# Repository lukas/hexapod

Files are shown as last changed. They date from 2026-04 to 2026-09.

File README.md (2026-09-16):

# Robotics projects

This repository contains the current hexapod work plus a small collection of
related robot builds and shared tooling. The hexapod history was extracted
(with full Git history and `exp/*` provenance tags) from the `weird_objects`
monorepo on 2026-08-29.

The top-level `hexapod_walker/` directory is kept intentionally — the RL
orchestrator, Makefiles, and provenance records use repo-root-relative
paths like `hexapod_walker/prototype_sts3215/...`, and preserving the
layout kept the extraction risk-free.

## Project families

- [`hexapod_walker/`](hexapod_walker/) — active hexapods, earlier actuator
  variants, and frozen walker generations.
- [`vehicles/`](vehicles/) — wheeled robot projects that do not share the
  hexapod architecture. The TT-motor kid truck lives here.
- [`tools/`](tools/) — repository-wide utilities used by more than one project.
- [`media/`](media/) — checked-in media referenced by project records.
- Robot Lab v2 (the experiment queue, loop and web/MCP service) lives in
  [lukas/hexapod-lab](https://github.com/lukas/hexapod-lab); it runs against a clone of this repo.

The current robot is
[`hexapod_walker/prototype_sts3215/`](hexapod_walker/prototype_sts3215/): an
18-servo Feetech STS3215 hexapod with MuJoCo/RL, robot control, and an
AprilTag tracker submodule. Start with that project's `README.md` and
`AGENTS.md`. The mechanical design (CAD, BOM, printing, BuildViz) is the
separate repo [lukas/hexapod-cad](https://github.com/lukas/hexapod-cad).

The hexapod has [two parallel walking goals](https://github.com/lukas/hexapod-orchestrator/blob/main/RL_GOALS.md):
smooth joystick control in simulation and on the physical robot by any
effective means, and that same result with walking learned entirely through RL without
demonstrations. The practical path keeps physical builds progressing while
the demonstration-free research continues.

`pyproject.toml` and `uv.lock` at the repository root define the ONE Python
environment for the whole repo: `uv sync` creates `.venv`, and `uv run ...`
uses it from any directory. The prototype packages are installed editable,
so `import rl_move` / `import hexapod_core` / the bare-module style used by
`linux_control/` and `motor_setup/` work without `sys.path` shims. `run.sh`
is the script runner the Makefiles use (it syncs the env, then runs a script
from its own directory).

The autonomous RL orchestrator (watcher, launcher, status server, MCP
server), the research-process rules (`RESEARCH_RULES.md`, `RL_PLAN.md`,
`RL_GOALS.md`, `EMERGENCY_HANDLING.md`, ...) and the runtime state it writes
(ledger, run stories, cycle log) live in their own repo,
[lukas/hexapod-orchestrator](https://github.com/lukas/hexapod-orchestrator). Sim tools here read the ledger
from `$HEXAPOD_STATE_DIR` (`rl_move/ledger.py`).

After a fresh clone, initialize the tracker submodule:

```sh
git submodule update --init --recursive
```

## Conventions

See `AGENTS.md` (uv, BuildViz, hardware safety) and `.cursor/rules/`
(local dev environment, worktrees, STS3215 hardware safety).

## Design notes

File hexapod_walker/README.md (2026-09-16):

# Hexapod Walker

A family of six-legged walking-robot designs, from a tabletop 3D-printed
prototype up to a human-carrying vehicle.

| Directory | What it is |
|---|---|
| [`prototype_sts3215/`](prototype_sts3215/) | **Current robot** — Feetech STS3215 serial-bus servos, Arduino UNO Q brain, full CAD validation pipeline, MuJoCo RL stack (its CoreWeave orchestrator is [lukas/hexapod-orchestrator](https://github.com/lukas/hexapod-orchestrator)), web control, and the `hexapod-tracker` submodule. See [`prototype_sts3215/PROTOTYPE.md`](prototype_sts3215/PROTOTYPE.md), [`prototype_sts3215/docs/CAD_WORKFLOW.md`](prototype_sts3215/docs/CAD_WORKFLOW.md), and the [`concepts/` index](prototype_sts3215/concepts/README.md). |
| `prototype_ak40/` | AK40-actuator concept variant; moved to [lukas/hexapod-cad](https://github.com/lukas/hexapod-cad) on 2026-09-15 with the rest of the CAD. |

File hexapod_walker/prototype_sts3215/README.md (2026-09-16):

# Hexapod STS3215 prototype

Tabletop 3D-printed hexapod driven by Feetech STS3215 bus servos and an
Arduino Uno Q. We pursue [two goals in parallel](https://github.com/lukas/hexapod-orchestrator/blob/main/RL_GOALS.md): smooth
joystick walking in simulation and on the physical robot by any effective
means, and the same outcome with
walking learned entirely through RL, without demonstrations. The first path
keeps physical builds progressing while the harder research continues.

The work is split into four areas that share the robot; start at the entry
point for the one you're working on:

| You are here to… | Start at |
|---|---|
| Design/print/assemble the robot (CAD, BOM) | separate repo: [lukas/hexapod-cad](https://github.com/lukas/hexapod-cad) (`PROTOTYPE.md` there) |
| Run the physical robot (firmware, control, safety) | `firmware/`, `linux_control/`, `rl_move/API.md` — **read the hardware-safety rules in the repo root `AGENTS.md` first** |
| Train it in simulation (RL campaign + autonomous agent loop) | [`rl_docs/README.md`](rl_docs/README.md) (doc index) here; the goals, plan, rules and the autonomous loop are the separate repo [lukas/hexapod-orchestrator](https://github.com/lukas/hexapod-orchestrator) (`RL_GOALS.md`, `RL_PLAN.md`, `RESEARCH_RULES.md` at its root) |
| See and steer either goal in simulation | [`sim_viewer/README.md`](sim_viewer/README.md) — viewer/joystick controls; verify the selected policy and configuration against the goal's demo evidence |
| Track it with cameras and AprilTags | [`hexapod-tracker/README.md`](hexapod-tracker/README.md) — standalone submodule with its own package, configs, UI, tests, and agent instructions |

## Status URLs

- Agent/orchestrator dashboard:
  `https://hexapod.cwd1f0-new-cluster.coreweave.app/now`
  (token-gated).
- Agent/LLM-readable status index:
  `https://hexapod.cwd1f0-new-cluster.coreweave.app/llms.txt`
  (no token).
- Local robot/sim control UI:
  `http://localhost:8898/rl`
  via `make web-8898-start`.

## Layout

| Path | What |
|---|---|
| `hexapod_core/` | The executable contracts every layer shares: `joint_frame.py` (joint order, names, servo ids), `geometry.py` (frozen CAD dimensions), gaits |
| `mujoco_prototype.py` | MuJoCo primitive model of the robot, built from `hexapod_core/geometry.py` |
| `mesh_mujoco/` | As-built MuJoCo mesh model; the STL assets and XML are tracked build products of [lukas/hexapod-cad](https://github.com/lukas/hexapod-cad) |
| [`docs/`](docs/) | Robot-side design notes still referenced by code; CAD, BOM and BuildViz docs live in hexapod-cad |
| `Makefile` | Tests, state pull, robot deploy, Mac hub |
| `firmware/` / `linux_control/` / `motor_setup/` | On-robot software |
| `hexapod-tracker/` | Git submodule containing AprilTag tracking, camera server/UI, configs, and off-robot vision tests |
| `rl_docs/` | RL campaign docs index: goal, operator wishlist, commands, log conventions |
| `rl_move/` | RL code: `sim/` (MuJoCo/MJX envs + training), robot-side control; the autonomous loop (watcher, launcher, guardrails) is [lukas/hexapod-orchestrator](https://github.com/lukas/hexapod-orchestrator) |
| `logs/` | Eval artifacts + per-experiment summaries (`logs/experiments/<run>/`) |
| `archive/` | Dated reviews, rulings, full plan/log history — search, don't read |

## Quick commands

Local Python convention: use `uv run python ...` or `uv run python -m ...`;
do not copy old bare `python3` examples from logs/archive. The repo-root
`AGENTS.md` and this project's `AGENTS.md` record the rule. Native
MuJoCo GUI/viewer launches on macOS are the special exception: use
`uv run mjpython ...` or the Makefile viewer targets.

After a fresh clone, initialize the tracker with `git submodule update --init`.

```sh
make -C hexapod_walker/prototype_sts3215 help
make -C hexapod_walker/prototype_sts3215 build
make -C hexapod_walker/prototype_sts3215 verify-fast
make -C hexapod_walker/prototype_sts3215 robot-check       # safe local robot/web checks
make -C hexapod_walker/prototype_sts3215 robot-deploy      # check + SSH deploy + remote health
make -C hexapod_walker/prototype_sts3215 web-8898-restart  # Mac hub: HTTPS :8443 + HTTP :8898
```

Robot-control dev loop details live in `linux_control/README.md` and
`linux_control/dev_loop.sh`. Use `robot-resolve` for a temporary IP when
`hexapod.local` is flaky; do not commit fixed board IPs.

The canonical local browser/control surface is `make -C
hexapod_walker/prototype_sts3215 web-8898-start`. It runs on the Mac via
`uv run`, manages a `launchctl` job, dynamically resolves the robot's
`:8080` service unless `HEXAPOD_HOST` is set, and serves
`https://localhost:8443/rl` for gamepad access, with the legacy
`http://localhost:8898/rl` still available. Accept the self-signed certificate
warning once. Use `web-8898-status`, `web-8898-restart`, `web-8898-stop`, and
`web-8898-logs` for operations.

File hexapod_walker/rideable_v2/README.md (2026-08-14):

# Rideable Hexapod Walker — `rideable_v2`

> A one-rider, six-legged walking vehicle sized to carry a **~77 kg
> (170 lb) rider** at a slow, statically-stable walk (~0.3 m/s). This is
> the **second rideable design iteration**: where
> [`../rideable_v1/`](../rideable_v1/README.md) was a ~360 kg, 72 V
> machine on twelve $1,515 RMD-X15s behind 6:1 duplex-chain secondaries,
> `v2` is a **~165 kg, 48 V machine on eighteen identical CubeMars
> AK80-64s** ($890, 850 g, 120 N·m peak each) behind **per-joint wide
> synchronous-belt stages** — 4:1 hip-pitch, 3:1 knee, 2:1 hip-yaw —
> with the **knee actuator relocated to the hip end of the femur** and
> every joint riding its **own large structural bearing**, not the
> motor's output bearing.
>
> **This is still a serious machine.** ~242 kg walking with a rider,
> a 12S lithium bus, and joints that can deliver 418 N·m. Read
> [§9 Safety](#9-safety--ballast-protocol) before building anything.
> **No rider until the machine has survived substantial ballast
> testing.**

`design_spec.yaml` is the machine-readable source of truth;
`tools/design_consistency_check.py` (run by `make check`) re-derives
every load, torque, belt tension, lock sizing, and power figure from it
and fails if these docs drift.

---

## 1. Documents in this directory

| File | What it covers |
|---|---|
| [`README.md`](README.md) *(this file)* | Overview, design basis, what changed vs v1 and vs the original brief, mass budget, cost roll-up, safety/ballast protocol. |
| [`DRIVETRAIN.md`](DRIVETRAIN.md) | The AK80-64 + belt-stage lineup, per-joint sizing and margins, the knee-motor-at-the-hip layout, the structural-joint-bearing load path, and the joint-side parking-pin load holding. |
| [`PARTS.md`](PARTS.md) | SKU-level part specs: belt/sprocket part numbers with center distances, bearing SKUs, lock hardware, electrical SKUs — the orderable detail behind `BOM.md`. |
| [`CHAIN_VARIANT.md`](CHAIN_VARIANT.md) | Alternative drivetrain: #40-2 duplex chain with flat-plate sprockets sized so every custom part cuts on a Makera Carvera — no outside machine shop. Same ratios; better hip margin (1.27×); chain-specific trade-offs stated. |
| [`STRUCTURE.md`](STRUCTURE.md) | Aluminum legs and the wide chassis: loads, sections, why 6061 works here where v1 needed 4130 steel. |
| [`POWER_SYSTEM.md`](POWER_SYSTEM.md) | The 12S (48 V-class) bus: contactor + pre-charge, **six fused leg branches**, the 24 V solenoid/logic rail, budgets, interlocks. |
| [`BOM.md`](BOM.md) | Orderable bill of materials with live-verified Aug-2026 prices. |
| [`design_spec.yaml`](design_spec.yaml) | Machine-readable design basis (checked by `make check`). |

> **Status: mechanical-design draft. Not built or tested.** Hand-calcs
> with single-digit-percent tolerance, plus first-pass FEA on the three
> flagged joint nodes (`tools/fea_joint_shaft.py`, `tools/fea_leg_nodes.py`
> — all SF ≥ 3.0 working); a real build still needs FEA of the machined
> geometry, a thermal model, and a controls-safety review. The BuildViz
> scene lives in
> `full_robot_viz/` (regenerate with `make viz`; `make check` runs the
> full geometry + articulation suite; view with `make view-buildviz`).
> Sustained cruise is the **ripple/wave gait** — tripod-walking runs the
> hips at ~104% of continuous torque and is for maneuvering only
> ([`DRIVETRAIN.md` §5](DRIVETRAIN.md#5-torque--speed-margins-against-the-design-basis)).

---

## 2. Design basis (decided)

| Parameter | Value | Notes |
|---|---|---|
| Purpose | Carry **1 rider, ~77 kg (170 lb)** | Private-property use only. |
| Cruise speed | **~0.3 m/s** (0.4 m/s stretch) | Statically stable at all times. |
| Total operating mass | **~242 kg** | 77 kg rider + **~165 kg vehicle (dry)**. |
| Ground weight | **~2.37 kN** | 242 kg × 9.81 m/s². |
| Gait | **Alternating tripod** (design gait) | Ripple/wave at creep speeds for a bigger polygon. |
| DOF | 6 legs × 3 DOF = **18 identical actuators** | hip-yaw, hip-pitch, knee — one SKU. |
| Per-leg foot load | **0.79 kN nominal / 1.19 kN design (1.5×)** | Tripod, 3 support legs. |
| Body | **~880 mm across the yaw axes** | "Wide body = stability without huge hip torque." |
| Leg | coxa 120 / **femur 350 / tibia 450 mm** | Per the brief. |
| Stance | Tucked — foot **0.30 m out / 0.55 m below** the hip-pitch joint | Foot radius 860 mm → **~1.72 m footprint**. |
| Hip-pitch torque | 0.24 kN·m parked / **0.36 kN·m design** (worst-in-stride arm 0.45 m) | The sizing driver. |
| Knee torque | 0.03 kN·m parked / **0.20 kN·m design** | Near-vertical tibia → tiny static arm (0.035 m). |
| Hip-yaw torque | ~0.03–0.08 kN·m | Friction + lateral imbalance only. |
| Joint speeds needed | ~31 °/s loaded (stance) / ~94 °/s unloaded (swing) | At 0.3 m/s tripod. |
| Rollover angle (CoM ~0.65 m) | **~49° parked on 6 feet / ~33° in tripod** | See §3. |

Everything downstream — actuator ratios, belt tensions, lock sizing,
structure, battery — is dimensioned to the **1.19 kN design foot load**
and the **0.36 kN·m design hip torque**.

---

## 3. What changed vs the brief (and vs `rideable_v1`)

The original v2 brief (AK80-64s + belt stages, knee motor inboard, wide
body, structural joint bearings, 48 V + contactor + six fused branches,
ballast before rider) **survives essentially intact** — it is the right
architecture, and the arithmetic checks out. Four things moved when the
numbers were run honestly:

1. **Continuous torque, not peak, is the binding constraint.** With a
   realistic 165 kg dry mass, the parked hip carries ~237 N·m static —
   but the 4:1 hip stage only delivers **~167 N·m continuous** (48 N·m
   rated × 4 × 0.87). The machine **cannot stand on motor current**, and
   a rideable spends most of its life standing. It therefore inherits
   v1's central *rule* — the machine never stands on motor current —
   implemented as **12 spring-applied parking pin locks** (hip-pitch +
   knee) that pin the driven pulley to the parent link at the joint.
   Power-off = pins in = rider supported. (The parts-spec pass showed
   COTS friction brakes at this torque are 4–8 kg each — ~50 kg for
   twelve — which is what forced, and improved, this design.)
   ([`DRIVETRAIN.md` §6](DRIVETRAIN.md#6-load-holding-joint-side-parking-pin-locks-v1s-rule-better-hardware))
2. **The hip peak margin is 1.16×, not "comfortable".** 418 N·m
   effective peak (120 × 4 × 0.87) vs 0.36 kN·m worst-in-stride. The
   architecture's own answer: **belt ratio is a pulley swap**, so 5:1
   (~1.47× margin, −20% speed) is a ~$150-per-joint tuning change after
   ballast testing, not a redesign. That tunability is a headline
   advantage of the belt stage over v1's chain-and-sprocket sets.
3. **The 2026 catalog check** (the brief asked for this): AK80-64 is
   current at **$889.90** (store.cubemars.com, Aug 2026). CubeMars also
   shipped the **AKH70-48** in 03/2026 — 222 N·m peak / 74 N·m rated,
   1.4 kg, dual-CAN, **$698.90, i.e. cheaper than the AK80-64 with ~2×
   the torque**. It does *not* make the external reduction unnecessary
   (the shock-isolation and structural-bearing arguments stand), but it
   is the designated **hip fallback at 3:1** if ballast testing shows the
   margin short.
4. **The ~45° rollover only holds parked.** On all six feet the support
   hexagon (inradius ~0.745 m) gives **~49°**; in tripod gait the
   3-foot triangle shrinks it to **~33°**. Still comfortable at 0.3 m/s
   — and the wide-body-over-long-legs logic is exactly why — but ride
   gait selection must respect the smaller number.

Vs **`rideable_v1`**, the wins compound: half the total mass (242 vs
460 kg) → a third of the hip torque (0.36 vs 1.2 kN·m) → belts become
buildable where v1's review killed them (3.3 kN of strand tension vs
8.2 kN) → aluminum legs replace welded 4130 truss → **~$35 k build vs
~$41 k** with a machine that is vastly less dangerous to develop. And
the joint-side parking pins delete v1's chain-snap single point of
failure outright.

---

## 4. How the subsystems fit together

```
                     rider (~77 kg) on saddle + footrests + harness
                                     │
                 ┌───────────────────┴───────────────────┐
                 │  CHASSIS: welded 6061 frame, ~880 mm   │
                 │  wide + deck, battery + e-bay low      │
                 └───────────────────┬───────────────────┘
                                     │ 6 identical legs, 60° apart
   ┌─────────────────────────────────┼─────────────────────────────────┐
   │ per leg — ALL THREE AK80-64s mounted at/near the body:            │
   │   yaw   AK80-64 → 2:1 belt → yaw joint bearing → coxa             │
   │   hip   AK80-64 → 4:1 belt → hip shaft/bearings [+ pin lock]      │
   │   knee  AK80-64 at the HIP end of the femur                       │
   │            └── 3:1 belt runs ~212 mm DOWN the femur ──► knee      │
   │                 shaft/bearings [+ pin lock] → tibia → sensing foot│
   └───────────────────────────────────────────────────────────────────┘

   mechanically:  motor → belt → LARGE bearing-supported joint shaft → leg
   electrically:  12S pack → fuse → pre-charge + contactor → 6 fused
                  leg branches → 18 × AK80-64 (CAN)   [POWER_SYSTEM.md]
```

* **Drivetrain ([`DRIVETRAIN.md`](DRIVETRAIN.md)).** One actuator SKU,
  three belt ratios tuned per joint. Effective joint figures (η = 0.87):
  hip **418 N·m peak / 167 cont / 72 °/s**, knee **313 / 125 / 96 °/s**,
  yaw **209 / 84 / 144 °/s**. The knee actuator lives at the hip end of
  the femur — moving that ~1.4 kg inboard cuts leg swing inertia
  ~20–25% and is why the machine will be markedly easier to control.
* **Load holding.** 12 spring-applied **parking pin locks** (hips +
  knees) engage hole rings machined into the driven pulleys; standing
  costs zero current. Because the pin holds **at the joint**, the belt
  is *not* in the holding load path — v1's chain-snap single point of
  failure is designed out.
* **Structure ([`STRUCTURE.md`](STRUCTURE.md)).** 6061-T6 aluminum
  box-section legs (~3.5 kg each), wide welded-tube chassis. Design
  foot load 1.19 kN is roughly *half* v1's, which is what lets aluminum
  replace steel truss.
* **Power ([`POWER_SYSTEM.md`](POWER_SYSTEM.md)).** One 12S (~44.4 V
  nom, 50.4 V full — the AK80-64's 12S max is why "48 V" means 12S)
  ~1.8 kWh pack → main fuse → pre-charge + contactor → **six 30 A fused
  leg branches**; a 48→24 V ≥350 W rail holds the 12 lock solenoids +
  logic.

---

## 5. Specification at a glance

| Property | Value |
|---|---|
| Configuration | 6 legs × 3 DOF, alternating tripod |
| Rider payload | 1 rider, ~77 kg (170 lb) |
| Vehicle dry mass | **~165 kg** |
| Total walking mass | **~242 kg** (~2.37 kN) |
| Cruise speed | ~0.3 m/s (0.4 stretch) |
| Footprint | Ø ~1.72 m; body ~880 mm wide; hip axis ~0.55 m up |
| Actuators | **18 × CubeMars AK80-64** (120 N·m pk / 48 N·m rated / 850 g) |
| Reductions | Wide synchronous belt: 4:1 hip / 3:1 knee / 2:1 yaw (η ≈ 0.87) |
| Joint capability | hip 418 N·m pk, 167 cont, 72 °/s · knee 313/125/96 · yaw 209/84/144 |
| Design joint loads | hip 0.36 kN·m · knee 0.20 kN·m · yaw 0.08 kN·m |
| Load-hold | 12 × joint-side parking pin, 540 N·m rated (power-off = pinned) |
| Battery | 12S Li-ion, ~40 Ah / ~1.8 kWh, ~10 kg |
| Power | ~0.9 kW cruise / ~1.8 kW peak walk / 70–90 A stand-up transient |
| Run time | ~2 h theoretical cruise → plan 45–75 min real |
| Drivetrain cost | **~$23.6 k** (18 actuators + 18 belt stages + 18 bearing sets + 12 locks) |
| Full build (est.) | **~$33 k (≈ $31–36 k)** |

---

## 6. Mass budget (~165 kg dry)

Order-of-magnitude, Aug 2026. The honest heavyweights are the belt
stages (a lightened 100T Ø255 mm pulley + belt + tensioner + guard is
~2.3 kg at the hip) and the chassis that must carry a rider on an
880 mm-wide frame. Rows are pinned by `tools/design_consistency_check.py`.

| System | Mass (kg) | Basis |
|---|---:|---|
| Actuators (18 × AK80-64 @ 0.85) | 15.3 | [BOM](BOM.md) |
| Belt stages (6 × [hip 2.3 + knee 2.2 + yaw 1.0]) | 33.0 | pulleys, belts, tensioners, guards |
| Structural joint bearings (18 sets @ ~1.0) | 18.0 | shafts, tapered/thin-section brgs, housings |
| Parking pin locks (12 @ ~0.35) | 4.2 | hips + knees, joint-side |
| Legs (6 × 6061 femur+tibia+hubs @ ~3.5) | 21.0 | [STRUCTURE](STRUCTURE.md) |
| Feet (6 × pad + load cell @ ~0.7) | 4.0 | |
| Chassis frame + deck (~880 mm wide) | 20.0 | |
| Saddle, pegs, bars, harness | 8.0 | |
| Battery (12S ~1.8 kWh) | 10.0 | [POWER_SYSTEM](POWER_SYSTEM.md) |
| Power electronics (contactor, fuses, DC-DC, wiring) | 5.0 | |
| Compute, IMU, sensors | 3.0 | |
| Fasteners, mounts, misc hardware | 8.0 | |
| Guards, covers, finishing | 2.0 | |
| **Subtotal** | **151.5** | |
| Contingency (~9%) | 13.5 | |
| **Total dry** | **~165** | |
| Rider | + ~77 | |
| **Total walking** | **~242** | matches [§2](#2-design-basis-decided) |

> **Mass discipline is a torque budget.** Every +10 kg dry adds
> ~15 N·m to the worst-in-stride hip torque (10 kg × g / 3 legs ×
> 0.45 m) and eats directly into the 1.16× hip margin. Weigh
> everything; treat the contingency row as a hard ceiling.

---

## 7. Cost roll-up

Full detail in [`BOM.md`](BOM.md). Headline:

| Bucket | Cost (USD, Aug 2026) |
|---|---:|
| 18 × AK80-64 @ $890 | $16,020 |
| 18 × belt stages (pulleys, Poly Chain belts, tensioners) | $4,080 |
| 18 × structural joint-bearing assemblies | $2,520 |
| 12 × parking pin locks | $960 |
| **Drivetrain subtotal** | **~$23,580** |
| Legs (6061 + machined hubs) | $2,000 |
| Feet + pads | $400 |
| Chassis + saddle + rider interface | $2,300 |
| Battery + power electronics | $1,200 |
| Compute, IMU, CAN, foot sensors | $1,700 |
| Fasteners, machining, misc | $1,500 |
| Consumables & finishing | $400 |
| **Full-build estimate** | **~$33,080 (≈ $31–36 k)** |

Swapping all 18 units to the AKH70-48 ($699) would save ~$3.4 k and
raise torque at the cost of speed and +10 kg of actuator mass — see
[`DRIVETRAIN.md` §7](DRIVETRAIN.md#7-the-akh70-48-alternative) before
ordering.

---

## 8. Design assumptions to confirm

1. **Vehicle dry mass ≤ 165 kg.** The hip margin dies quickly above it
   (§6 note). Weigh subassemblies against the budget as they are built.
2. **Belt allowable (~7.7 kN class for 8MGT × 36 mm)** — now
   catalog-anchored (the Gates manual's own 12 mm worked example runs
   ~2.6 kN; Table 11 width constants scale 36 mm to ~3×), giving the
   hip's 3.28 kN peak >2× margin. Have Gates application engineering
   sign off the final drives at order time. Fallbacks: 5:1 hip ratio,
   or v1's duplex #40 chain at the hip only.
3. **Belt-stage efficiency ~0.87** (the brief's 85–90%). All joint
   torque figures include it.
4. **Moment arms**: hip 0.30 m static / 0.45 m worst-in-stride
   (±0.15 m stride excursion); knee 0.035/0.185 m from the solved
   tucked pose. If the gait sweeps further, torque climbs
   proportionally.
5. **AK80-64 figures** (120/48 N·m, 48 rpm rated @ 48 V, 850 g, 12S
   max, $890) live-verified Aug 2026 — re-verify at order time,
   including whether the store price includes the driver board.
6. **Uneven load share**: a tripod handover can briefly put ~half the
   vehicle weight on one leg (~1.19 kN — exactly the design foot
   load). The controller must not park in a two-leg-dominant stance.
7. **The rider is on a suspension saddle**, so gait bob is comfort, not
   structure — but the CoM-height ~0.65 m rollover numbers assume the
   rider sits, not stands.

---

## 9. Safety & ballast protocol

Non-negotiables, inherited from v1 and extended:

* **The parking pin locks are the primary safety system.** Power-off =
  pins in = legs locked with the rider supported (each joint settles
  ≤15° to the next lock hole). The hardware e-stop must **remove
  power** (contactor + solenoid rail), not merely command zero torque.
* **The pins hold at the joint, so the belt is NOT in the holding load
  path** — a snapped belt loses drive, not support. Belt inspection is
  ordinary maintenance, not a safety item (v1's chain caveat, deleted
  by design).
* **Controlled stops sequence:** freeze gait → plant a valid tripod →
  align joints to lock holes → drop pins. Never pin mid-swing except in
  an already-detected emergency.
* **12S lithium (50.4 V full) below the 60 V LV line but still an arc
  and fire hazard**: main fuse at the pack, pre-charge before contactor
  close, six fused branches, bleed indicator, charge on a balance
  charger in a fire-safe area.
* **Mechanical travel stops on every joint** (per the brief) sized to
  take a full-torque runaway without letting links collide.
* **No rider until ballast testing passes, in stages:**
  1. Single-joint bench rig (see [`BOM.md` §L](BOM.md#l-bench-test-order-de-risk-before-buying-18)).
  2. Full machine, **no ballast**: stand-up, stand-down, tripod walk.
  3. **40 kg ballast** (half rider): 10 h cumulative walking, pin
     locks hold at zero current, deliberate e-stops mid-walk.
  4. **80 kg ballast** (≥ rider): repeat, plus worst-case stances,
     slope tests to the rollover margin, and a deliberate
     single-motor-disable walk-home test.
  5. Only then a rider, with harness, helmet, spotters, and the e-stop
     tested that same session.
* **Private property only.** A ~165 kg walking vehicle is not
  street-legal in most jurisdictions.
* **Professional review required** before any rider: FEA on legs and
  chassis, thermal model of the actuator+belt stack, controls-safety
  review of the e-stop/lock interlock.

---

## 10. License

Personal exploration — no license declared yet, same as the parent
project.

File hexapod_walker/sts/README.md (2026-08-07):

# STS3215 walking (sim + RL + stall safe-stop)

Focused walking stack for the Feetech STS3215 tabletop hexapod. Reuses the
MuJoCo model / tripod gait from [`../prototype_sts3215/`](../prototype_sts3215/)
but trains a policy on **the same sensor channels the real bus returns**:

| Channel | Source on robot | Sim model |
|---|---|---|
| position (deg) | 12-bit encoder | quantized `qpos` + noise |
| speed (deg/s) | STS present-speed | `qvel` + noise |
| load (%) | present-load register | `|τ| / τ_stall × 100` |
| current (A) | present-current (6.5 mA/LSB) | `I_idle + (I_stall−I_idle)·|τ|/τ_stall` |
| voltage (V) | present-voltage | 12 V − bus sag |
| temperature (°C) | present-temperature | I²R + cooling |

Stall safe-stop (sim and hardware): if a joint stays near-stopped **and**
near-stall load/current for ~120 ms, freeze targets at the last pose, then
torque-off (`relax`) so the motor is not cooked against a jam.

Sit / stand: ~40% of training episodes practise transitioning between a
**legs-out-wide sprawl** (chassis low) and the normal standing stance.  The
nominal motion is a **4–7 s** cosine blend; the policy may only *slow* it
further (rate ∈ [0.4, 1.0]) and is rewarded for staying under soft current
limits:

- position-actuator torque capped at ~2.10 N·m (~71% stall)
- soft/hard per-servo current: 1.05 A / 1.80 A (truncate above hard)
- soft/hard bus current: 12 A / 18 A
- amp-second energy penalty on both walk and posture

so it learns thrifty stand-ups and gaits — the open-loop slam that hit ~29 A
was a demo discontinuity, not a trained behaviour.

## Layout

| File | Role |
|---|---|
| `sts_sensors.py` | STS electrical + encoder model |
| `stall_guard.py` | Stall FSM (NORMAL → HOLD → RELAX) |
| `posture.py` | Sit (sprawl) / stand joint targets + blend |
| `sts_env.py` | Gymnasium env (walk + posture + motor obs) |
| `train.py` | PPO training entrypoint |
| `rollout.py` | Watch a trained policy in MuJoCo |
| `controller.py` | Deploy-time policy + guard (sim or `FeetechBus`) |

## Quick start

```sh
# Watch sit → stand → walk with live total bus amps (viewer + terminal bar)
./.venv/bin/mjpython hexapod_walker/sts/demo_amps.py

# Smoke the env (walk + stand-up/sit-down currents + stall trip)
./.venv/bin/python hexapod_walker/sts/sts_env.py

# Short train (walk + sit/stand mix)
./.venv/bin/python hexapod_walker/sts/train.py --steps 5000 --n-envs 1

# Real training run
./.venv/bin/python hexapod_walker/sts/train.py --steps 300000 --n-envs 8

# Posture-only or walk-only
./.venv/bin/python hexapod_walker/sts/train.py --steps 200000 --posture-only
./.venv/bin/python hexapod_walker/sts/train.py --steps 200000 --no-posture

# Roll out walk / stand-up / sit-down
./.venv/bin/python hexapod_walker/sts/rollout.py \
  --policy hexapod_walker/sts/policies/sts_ppo/sts_ppo.zip \
  --vx 0.10 --headless
./.venv/bin/python hexapod_walker/sts/rollout.py \
  --policy hexapod_walker/sts/policies/sts_ppo/sts_ppo.zip \
  --mode posture --posture stand --headless --duration 5
./.venv/bin/python hexapod_walker/sts/rollout.py \
  --policy hexapod_walker/sts/policies/sts_ppo/sts_ppo.zip \
  --mode posture --posture sit --headless --duration 5

# Demo the stall guard mid-walk
./.venv/bin/python hexapod_walker/sts/rollout.py \
  --policy hexapod_walker/sts/policies/sts_ppo/sts_ppo.zip \
  --jam --headless --duration 6
```

## Observation contract

Leading dims match the residual-gait walker (joint state, chassis twist,
contacts, command, gait phase, optional gait scales / swing mask), except
joint pos/vel are **STS-encoder-derived**, not privileged MuJoCo state.
Trailing motor dims (57):

```
load_pct/100 ×18 | current/I_stall ×18 | bus_V/12 | mean_temp/100
| stall_severity | per-joint stall-accumulator ×18
```

That last block is what makes the policy robust to torque/amp feedback:
it can feel a joint climbing toward stall and back off *before* the guard
trips.  If it still trips, the episode ends with a stall penalty and the
controller freezes / relaxes.

Trailing posture dims (3): `mode` (0=walk, 1=posture), `posture_cmd`
(0=sit, 1=stand), `blend_alpha` (0→1 through the cosine transition).

## Hardware bridge

`controller.apply_to_bus(bus, result)` writes targets through
`prototype_sts3215/motor_setup/feetech_bus.py`.  On `relax=True` it
torque-offs every servo.  On `stall=True` (freeze before relax) it uses
a gentle hold profile (`speed≈250`) — Feetech `speed=0` means *max*,
not stop.  End a session with `safe_stop_walk(bus)` (soft-hold, keep
supporting torque).  Build the observation’s leading slice from IMU +
the same `read_feedback` dicts the policy already expects for the
trailing slice (`feedback_dicts_to_array`).

## Constants

Aligned with `prototype_sts3215/standup_current_sim.py` and WIRING.md:

- `τ_stall = 2.94 N·m` (30 kg·cm @ 12 V)
- `I_stall = 2.7 A`, `I_idle = 0.2 A`
- Sim actuator `forcerange` ceiling set to `2.7 N·m`

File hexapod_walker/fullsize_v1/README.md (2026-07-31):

# Human-Carrying Hexapod Walker

A parametric STL generator for a **human-rider-sized six-legged walking
vehicle.** One Python script (`hexapod_walker.py`) emits 11 individual
STL parts plus an assembly-preview STL of the whole vehicle in standing
pose. A second script (`build_full_assembly.py`) emits a fully-dressed
assembly — frame, 18 motor housings, battery + cells, foot rubber,
saddle padding, and a stylized seated rider — split into 5 category
STLs that the Blender render script materials separately.

* Vehicle envelope: ~ 4.0 m foot-to-foot, ~ 1.3 m saddle height
* Payload: 1 rider, ≤ 110 kg
* 18 actuators (3 DOF × 6 legs), driven by industrial harmonic-drive servos
* Total dry mass ~ 280 kg
* See [`ASSEMBLY.md`](ASSEMBLY.md) for the full build guide, BOM, motor
  selection, electronics, gait, and safety notes.

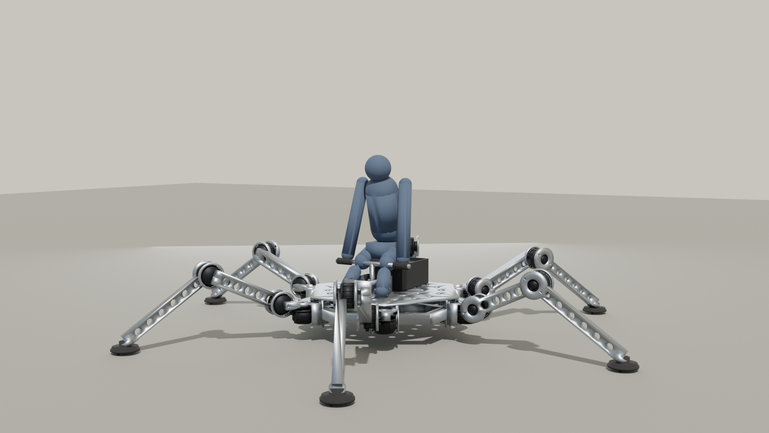
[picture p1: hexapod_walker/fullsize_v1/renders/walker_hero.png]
Cycles render of the hexapod walker with seated rider for scale


> **Looking for a cheap way to prove the kinematics first?**
> See the [tabletop prototype](#tabletop-prototype) section below for a
> ~ 60 cm, ~ 1.3 kg sibling design that runs on $13 hobby servos and
> 3D-printed PLA — same architecture, same gait, ~ $200 BOM, walks in
> a weekend. Full guide: [`prototype_sts3215/PROTOTYPE.md`](../prototype_sts3215/PROTOTYPE.md).

## Quick start

```bash
# from the repo root
./run.sh hexapod_walker/fullsize_v1/hexapod_walker.py        # 11 fabricable STLs
./run.sh hexapod_walker/fullsize_v1/build_full_assembly.py   # full-assembly category STLs
./hexapod_walker/fullsize_v1/render_blender.sh \              # photoreal Cycles render
    --device METAL --samples 256 \
    --out hexapod_walker/fullsize_v1/renders/walker_hero.png
```

## Generate the fabricable STLs

```bash
./run.sh hexapod_walker/fullsize_v1/hexapod_walker.py
```

This creates `hexapod_walker/fullsize_v1/stl/` containing:

| File | Qty for one vehicle | Recommended fabrication |
|---|---|---|
| `chassis_hex.stl` | 1 | Welded 80 × 80 × 6 mm sq. tube + plate, painted |
| `chassis_top_deck.stl` | 1 | 12 mm 6061-T6, CNC water-jet |
| `saddle_mount.stl` | 1 | CNC 6061-T6 or MJF PA12-CF |
| `battery_box.stl` | 1 | MJF PA12-CF or welded 3 mm aluminum |
| `electronics_bay.stl` | 1 | MJF PA12-CF |
| `coxa_bracket.stl` | 6 | CNC 6061-T6 or investment-cast A356 |
| `coxa_link.stl` | 6 | CNC 6061-T6 or investment-cast A356 |
| `femur_link.stl` | 6 | CNC end caps on a 90 × 120 × 6 mm Al extrusion |
| `tibia_link.stl` | 6 | CNC end caps on a 70 × 90 × 5 mm Al extrusion |
| `foot_pad.stl` | 6 (used as mould patterns) | 60-A urethane around a 6 mm steel disc |
| `motor_flange.stl` | 18 | MJF PA12-CF or CNC 6061-T6 |
| `assembly_preview.stl` | 0 (visualization only) | Open in MeshLab / Cursor STL viewer |

All 11 individual parts are watertight manifolds and load directly into
slicers and CAM software. The assembly preview is a visualisation
aggregate (overlapping parts, not booleaned) — don't try to slice it.

## Generate the full assembly + render

`build_full_assembly.py` emits a *visual* assembly that includes
everything you'd need to ship a finished walker — not just the
fabricable parts:

```bash
./run.sh hexapod_walker/fullsize_v1/build_full_assembly.py
```

This writes 6 STL files into `assembly/`:

| File | Contents | Material in render |
|---|---|---|
| `frame.stl` | Chassis + top deck + 6 × {coxa bracket, coxa link, femur, tibia} + saddle post + handlebars + electronics bay | Brushed satin aluminum |
| `motors.stl`  | 18 × harmonic-drive servo housings (with cooling fins, output flanges, encoder caps) at every joint | Dark anodized aluminum |
| `battery.stl` | Battery enclosure + 2 × visible LiFePO₄ cell packs | Matte black powder-coat |
| `soft.stl` | Urethane foot pads + saddle pad + saddle backrest + handlebar grips | Black rubber / leather |
| `rider.stl` | Stylized 1.75 m seated rider (head, torso, arms gripping bars, legs on footrests) — for scale | Denim grey |
| `full.stl` | All five categories merged into one mesh — drop-in for non-Blender STL viewers | n/a |

Then run the Blender render (Cycles, denoised):

```bash
./hexapod_walker/fullsize_v1/render_blender.sh                                # default
./hexapod_walker/fullsize_v1/render_blender.sh --device METAL --samples 256   # GPU + nicer
./hexapod_walker/fullsize_v1/render_blender.sh --camera-azimuth-deg 90        # side view
```

The wrapper auto-locates Blender, rebuilds the assembly STLs if any are
missing or stale, and runs `render_blender.py` headless. Default output
is `renders/walker.png` (1600 × 1000); a typical Cycles render on Apple
Silicon's `METAL` backend takes ~ 10 s at 96 samples or ~ 30 s at 256.

## Customising the design

Every dimension is a named constant near the top of
[`hexapod_walker.py`](hexapod_walker.py). The most useful knobs:

| Constant | Default | Tweak this if... |
|---|---|---|
| `CHASSIS_FLAT_TO_FLAT` | 1200 mm | You want a wider/narrower body |
| `COXA_LENGTH` | 150 mm | Hip-yaw axis ↔ hip-pitch axis offset |
| `FEMUR_LENGTH` | 600 mm | Thigh length |
| `TIBIA_LENGTH` | 800 mm | Shin length |
| `MOTOR_OD`, `MOTOR_BOLT_CIRCLE`, `MOTOR_LENGTH` | matched to Harmonic Drive FHA-40C | Your chosen servomotor has a different flange |
| `STANCE_FEMUR_DEG`, `STANCE_TIBIA_DEG` | -25°, +60° | Different ride height in the preview |

After editing, re-run `./run.sh hexapod_walker/fullsize_v1/hexapod_walker.py` —
expect ~ 1.5 s for a full regeneration.

## MuJoCo physics simulation

The MJCF model in [`mujoco_walker.py`](mujoco_walker.py) wires the existing
STL parts into a fully dynamic six-legged robot: chassis + saddled rider
(visual only — its mass is lumped into the chassis), 18 hinge joints (yaw,
hip pitch, knee per leg) driven by industrial-class PD position actuators,
and an alternating-tripod gait built on 3-DOF inverse kinematics.  The
controller takes a body-frame **twist `(vx, vy, ω)`** so it strafes,
spins and curves natively without re-aiming the chassis first.

The world includes a procedurally generated 36 m × 36 m heightfield
terrain (low-frequency sinusoidal hills + scattered Gaussian bumps, peak
~ 0.20 m) with a flat 2.5 m spawn pad around the origin, plus a backup
ground plane in case you wander off the hfield.  On top of the terrain
we scatter ~ 14 procedural **static obstacles** (brown crates, grey
pillars, orange low curbs you can step onto, red blocks you walk
around, angled grey ramps, yellow bollards), each rested on the local
hfield elevation and never inside the spawn pad.

```bash
# install once
./.venv/bin/pip install 'mujoco==2.3.7'

# interactive 3D viewer (uses mjpython on macOS)
./run.sh hexapod_walker/fullsize_v1/mujoco_walker.py

# start moving immediately
./run.sh hexapod_walker/fullsize_v1/mujoco_walker.py --vx 0.4 --omega 0.05

# headless: simulate N seconds, print chassis trajectory
./run.sh hexapod_walker/fullsize_v1/mujoco_walker.py --headless --duration 8.0 --vx 0.4

# strafe sideways, curve, spin in place, etc.
./run.sh hexapod_walker/fullsize_v1/mujoco_walker.py --vy 0.4                    # +Y strafe
./run.sh hexapod_walker/fullsize_v1/mujoco_walker.py --vx 0.3 --omega 0.10       # left curve
./run.sh hexapod_walker/fullsize_v1/mujoco_walker.py --omega 0.15                # spin

# disable terrain / pick a different world / change obstacle layout
./run.sh hexapod_walker/fullsize_v1/mujoco_walker.py --no-terrain
./run.sh hexapod_walker/fullsize_v1/mujoco_walker.py --terrain-seed 7
./run.sh hexapod_walker/fullsize_v1/mujoco_walker.py --obstacles 30           # busier
./run.sh hexapod_walker/fullsize_v1/mujoco_walker.py --obstacles 0            # clear
./run.sh hexapod_walker/fullsize_v1/mujoco_walker.py --obstacle-seed 42

# dump the generated MJCF for inspection
./run.sh hexapod_walker/fullsize_v1/mujoco_walker.py --dump-xml hexapod_walker/fullsize_v1/walker.xml
```

### Live keyboard controls (focus the MuJoCo window)

The walker's WASD-style command keys are deliberately mapped to keys
**MuJoCo's own viewer doesn't already bind**, since the viewer takes most
letter keys for visualization flags (`W` = wireframe, `C` = contacts,
`F` = forces, `T` = transparency, `R` = record video, `Space` = pause,
`0`..`5` = geom-group toggles, etc.).

| Key | Action |
|---|---|
| `↑` / `↓` | forward / back  (body-frame +X / −X), ±0.15 m/s per tap |
| `←` / `→` | strafe left / right (+Y / −Y), ±0.15 m/s per tap |
| `Page Up` / `Page Down` | turn left / right (+CCW / −CW), ±0.10 rad/s per tap |
| `Home` | full stop (zero `vx`, `vy`, `omega`) |
| `End` | teleport chassis back to spawn pad + stop |
| `Insert` / `Delete` | scale current twist by 1.5× / 0.5× |
| `` ` `` (backtick) | print help + current twist |

Each twist component has hard caps (`MAX_VX = MAX_VY = 1.5 m/s`,
`MAX_OMEGA = 0.6 rad/s`) and is low-pass-filtered to ~ 200 ms before
being passed to the gait, so key presses never shock the joints.
Steady-state translation tops out around 0.30–0.35 m/s on flat ground;
heavier strides than that overstretch the leg's IK envelope and the
chassis sags.

The MuJoCo viewer's own keys still work in parallel:
**`Space`** pauses the simulation, **`Tab`** hides the side panel,
**`Backspace`** snaps back to the MJCF keyframe, mouse-drag orbits the
camera, and `Ctrl+drag` on a body applies a force/torque impulse.

### Headless trajectory CLI

`--vx`, `--vy`, `--omega` set the twist directly.  The legacy
`--stride` / `--fwd-dir` / `--turn` flags still work and are mapped to
twist internally.  See the headless test recipes in
[`mujoco_walker.py`](mujoco_walker.py)'s docstring.

## Reinforcement-learning gait improvement

The MuJoCo simulation is wrapped in a Gymnasium-compatible environment
([`hexapod_env.py`](hexapod_env.py)) so you can use any RL library
(Stable Baselines3, CleanRL, rl_games, RLlib, …) to **improve the gait
on top of the analytic IK controller**.  Two action spaces are exposed,
selected by the `gait_action` flag:

| `gait_action` | action dim | what the policy outputs |
|---|---|---|
| `False` *(default — used by `walker_v6`)* | **18** | per-joint position residual added to the IK gait, scaled to ±0.05 rad |
| `True`  *(used by `walker_v7`/`v8`/`v9`)*  | **21** | the same 18 residuals plus 3 trailing dims that modulate **(period, lift, stride)** scales of the underlying tripod gait |

* **Observation (57- or 60-dim)** — joint pos/vel, chassis pose &
  body-frame twist, six foot-touch sensors, commanded `(vx, vy, ω)`,
  `(sin, cos)` of the *stateful* gait phase, and (when
  `gait_action=True`) the three currently-applied gait scales.
* **Reward (per 50 Hz step)** — exponential twist-tracking + uprightness
  bonus − tilt − action norm − action delta − (small) joint-acceleration
  − fall penalty + alive bonus.  All terms are weighted by env knobs
  (`track_w_v`, `delta_w`, `progress_w`, …) so the same code reproduces
  every policy listed below from a single `env_cfg.json`.
* **Domain randomisation** — chassis mass ±25 %, ground friction ±50 %,
  motor latency 0–60 ms, per-joint position bias ±0.015 rad, action
  noise std 0.05, and an optional starting velocity kick.  All gated on
  individual `dr_*` env knobs (set to 0 to disable).
* **Terrain curriculum** — the heightfield intensity ramps from
  `terrain_level_min` to `terrain_level_max` over `curriculum_episodes`
  resets, so early training is on flat ground and later episodes add
  bumps gradually.
* **Long-horizon recovery (`walker_v9`)** — two training-only knobs that
  teach the policy to handle the full operating envelope rather than
  just an 8 s window:
    * `cmd_resample_seconds` re-rolls the commanded twist mid-episode so
      the policy must learn graceful direction changes (forward → strafe
      → reverse → spin) instead of memorising one direction per
      episode.
    * `terminate_on_stuck_seconds` ends the episode early (truncation,
      no fall penalty) when the chassis hasn't moved >5 cm in N
      seconds, providing an explicit "you got pinned" training signal.
  Both default to 0 (disabled) and are ignored by the eval scripts so
  benchmarking stays apples-to-apples.
* **Proprioceptive stub-avoider (`walker_v10`)** — teaches the walker
  to high-step over obstacles without any forward-looking sensors.
  Three changes on top of v9:
    * `per_leg_lift=True` splits the gait's lift-scale dim into 6 per-leg
      dims, so the policy can lift just the leg that's in trouble instead
      of raising the whole gait (action grows from 21 to 26 dims, obs
      from 60 to 71).
    * The 6 obs additions are 6 binary swing-mask flags fused with the
      existing 6 foot-touch sensors, giving the policy a direct
      "this swing leg is in contact with something" signal.
    * `stub_w * Σ swing[i] · touch[i] · dt` is subtracted from the reward
      every control step.  The integral runs *inside* the inner sim loop
      so brief mid-step stubs aren't missed.  Net effect: the policy
      learns "if I bang my swing foot, I should pause/lift it higher"
      purely from proprioception, no exteroception needed.
* **Randomisation** — terrain seed, obstacle seed, and the commanded
  twist are also re-rolled every episode.

### Live viewer + headless rollout

```bash
# install the RL stack once (mujoco / gymnasium / stable-baselines3 / torch)
./.venv/bin/pip install -r requirements.txt

# smoke test the env (40 steps with zero residuals)
./.venv/bin/python hexapod_walker/fullsize_v1/hexapod_env.py

# live MuJoCo viewer driven by the recommended deployment policy
./hexapod_walker/fullsize_v1/run_policy.sh v9 0.4 4
#                              ^   ^   ^
#                              tag vx  obstacles

# headless evaluation: per-episode tracking score + distance
./.venv/bin/python hexapod_walker/fullsize_v1/rollout_walker.py \
    --policy hexapod_walker/fullsize_v1/policies/walker_v9/walker_v9.zip \
    --headless --episodes 5 --vx 0.4

# fixed 10-command benchmark (matches the table below)
./.venv/bin/python hexapod_walker/fullsize_v1/eval_walker.py \
    --policy hexapod_walker/fullsize_v1/policies/walker_v9/walker_v9.zip --quiet

# robustness sweep under mass / friction / latency / bias / vel-kick
./.venv/bin/python hexapod_walker/fullsize_v1/eval_perturbed.py \
    --policies baseline \
        hexapod_walker/fullsize_v1/policies/walker_v6/walker_v6.zip \
        hexapod_walker/fullsize_v1/policies/walker_v8/walker_v8.zip \
        hexapod_walker/fullsize_v1/policies/walker_v9/walker_v9.zip
```

`rollout_walker.py` and the two eval scripts auto-load `env_cfg.json`
next to the policy, so they always rebuild the environment with the
exact action space, gait period, residual scale, and gait-scale ranges
the policy was trained against — no manual flag-juggling.

### Reproducing each policy

`train_walker.py` exposes every relevant knob on the CLI and writes the
full configuration to `policies/<tag>/env_cfg.json` for later eval/rollout.
The four policies that ship in `policies/` were trained with:

```bash
# walker_v6 — residual-only (18-dim action), DR + curriculum
./.venv/bin/python hexapod_walker/fullsize_v1/train_walker.py \
    --steps 5000000 --n-envs 8 --tag walker_v6 \
    --residual-scale 0.05 --gait-period 1.0 --action-filter-tau 0.10 \
    --delta-w 3.0 --cmd-speed-bias 0.4 \
    --vx-max 0.55 --vy-max 0.35 --omega-max 0.20 \
    --net-arch 256,256 --log-std-init -1.7 \
    --dr-mass-pct 0.25 --dr-friction-pct 0.5 \
    --dr-motor-latency-ms 60 --dr-joint-bias-rad 0.015 \
    --dr-action-noise 0.05 --dr-velocity-kick 0.05 \
    --terrain-level-max 1.0 --curriculum-episodes 800

# walker_v8 — parameterised gait (21-dim action), tightened ranges,
#             lower LR so PPO actually converges
./.venv/bin/python hexapod_walker/fullsize_v1/train_walker.py \
    --steps 5000000 --n-envs 8 --tag walker_v8 \
    --gait-action \
    --period-scale-range 0.85,1.15 \
    --lift-scale-range   0.8,1.4 \
    --stride-scale-range 0.85,1.15 \
    --gait-action-filter-tau 0.30 \
    --residual-scale 0.05 --gait-period 1.0 --action-filter-tau 0.10 \
    --delta-w 3.0 --cmd-speed-bias 0.4 \
    --vx-max 0.55 --vy-max 0.35 --omega-max 0.20 \
    --net-arch 256,256 --log-std-init -1.7 \
    --learning-rate 1.5e-4 --n-epochs 6 --n-steps 4096 \
    --dr-mass-pct 0.25 --dr-friction-pct 0.5 \
    --dr-motor-latency-ms 60 --dr-joint-bias-rad 0.015 \
    --dr-action-noise 0.05 --dr-velocity-kick 0.05 \
    --terrain-level-max 1.0 --curriculum-episodes 800

# walker_v9 — v8 trained for long-horizon recovery: 16 s episodes,
#             mid-episode command resampling, stuck-termination signal,
#             12 obstacles, slightly looser smoothness penalty
./.venv/bin/python hexapod_walker/fullsize_v1/train_walker.py \
    --steps 6000000 --n-envs 8 --tag walker_v9 \
    --gait-action \
    --episode-seconds 16.0 \
    --cmd-resample-seconds 5.0 \
    --terminate-on-stuck-seconds 4.0 \
    --obstacle-count 12 \
    --period-scale-range 0.85,1.15 \
    --lift-scale-range   0.7,1.5 \
    --stride-scale-range 0.85,1.15 \
    --gait-action-filter-tau 0.30 \
    --residual-scale 0.05 --gait-period 1.0 --action-filter-tau 0.10 \
    --delta-w 2.0 --cmd-speed-bias 0.4 \
    --vx-max 0.55 --vy-max 0.35 --omega-max 0.20 \
    --net-arch 256,256 --log-std-init -1.7 \
    --learning-rate 1.5e-4 --n-epochs 6 --n-steps 4096 \
    --dr-mass-pct 0.25 --dr-friction-pct 0.5 \
    --dr-motor-latency-ms 60 --dr-joint-bias-rad 0.015 \
    --dr-action-noise 0.05 --dr-velocity-kick 0.05 \
    --terrain-level-max 1.0 --curriculum-episodes 800

# walker_v10 — v9 + proprioceptive stub-avoider: per-leg lift action,
#              swing-mask obs, swing-foot contact penalty, dense
#              obstacle field, wider lift / period ranges so the
#              policy can pause and high-step over a stub.
./.venv/bin/python hexapod_walker/fullsize_v1/train_walker.py \
    --steps 6000000 --n-envs 8 --tag walker_v10 \
    --gait-action --per-leg-lift --stub-w 0.5 \
    --episode-seconds 16.0 \
    --cmd-resample-seconds 5.0 \
    --terminate-on-stuck-seconds 4.0 \
    --obstacle-count 20 \
    --period-scale-range 0.60,1.60 \
    --lift-scale-range   0.40,2.50 \
    --stride-scale-range 0.85,1.15 \
    --gait-action-filter-tau 0.30 \
    --residual-scale 0.05 --gait-period 1.0 --action-filter-tau 0.10 \
    --delta-w 1.5 --cmd-speed-bias 0.4 \
    --vx-max 0.55 --vy-max 0.35 --omega-max 0.20 \
    --net-arch 256,256 --log-std-init -1.7 \
    --learning-rate 1.5e-4 --n-epochs 6 --n-steps 4096 \
    --dr-mass-pct 0.25 --dr-friction-pct 0.5 \
    --dr-motor-latency-ms 60 --dr-joint-bias-rad 0.015 \
    --dr-action-noise 0.05 --dr-velocity-kick 0.05 \
    --terrain-level-max 1.0 --curriculum-episodes 800

# walker_v11 — narrow-stance variant of v10.  ``--stance-radius-scale
#              0.70`` shrinks the foot's body-frame radial distance to
#              70 % of the wide spider stance, producing a more
#              compact dog-like silhouette.  The IK absorbs the
#              change as deeper knee bend; the chassis stays at the
#              same height because the foot's z-below-hip is preserved.
#              Knee + pitch joint ranges in the MJCF were widened
#              accordingly (knee 1.7 → 2.7 rad, pitch lower bound
#              -1.4 → -1.6 rad) -- existing policies stay inside the
#              old ranges so they're unaffected.
./.venv/bin/python hexapod_walker/fullsize_v1/train_walker.py \
    --steps 6000000 --n-envs 8 --tag walker_v11 \
    --gait-action --per-leg-lift --stub-w 0.5 \
    --stance-radius-scale 0.70 \
    --episode-seconds 16.0 \
    --cmd-resample-seconds 5.0 \
    --terminate-on-stuck-seconds 4.0 \
    --obstacle-count 20 \
    --period-scale-range 0.60,1.60 \
    --lift-scale-range   0.40,2.50 \
    --stride-scale-range 0.85,1.15 \
    --gait-action-filter-tau 0.30 \
    --residual-scale 0.05 --gait-period 1.0 --action-filter-tau 0.10 \
    --delta-w 1.5 --cmd-speed-bias 0.4 \
    --vx-max 0.55 --vy-max 0.35 --omega-max 0.20 \
    --net-arch 256,256 --log-std-init -1.7 \
    --learning-rate 1.5e-4 --n-epochs 6 --n-steps 4096 \
    --dr-mass-pct 0.25 --dr-friction-pct 0.5 \
    --dr-motor-latency-ms 60 --dr-joint-bias-rad 0.015 \
    --dr-action-noise 0.05 --dr-velocity-kick 0.05 \
    --terrain-level-max 1.0 --curriculum-episodes 800
```

Each run takes ≈ 16 minutes on an 8-core CPU (~5 k env-steps/s).  When
resuming from a checkpoint with `--resume`, the LR / `ent_coef` /
`n_epochs` / `n_steps` flags now override whatever was saved in the
`.zip`, so you can refine a converged policy at a smaller learning rate
without recreating it from scratch.

### Measured results

Tracking score on a fixed 10-command suite (3 terrain × 6 s episodes
each, max ≈ 1.5):

| perturbation | baseline | v6 | **v8** | v9 |
|---|---:|---:|---:|---:|
| nominal | 1.246 | 1.256  | **1.277** | 1.262  |
| +25 % chassis mass | 1.243 | 1.255  | **1.275** | 1.263  |
| −40 % friction | 1.246 | 1.256  | **1.277** | 1.262  |
| 60 ms motor latency  | 1.246 | 1.260  | **1.280** | 1.263  |
| 1.5° joint bias | 1.177 | 1.245  | **1.260** | 1.244  |
| 0.15 m/s vel kick | 1.246 | 1.256  | **1.277** | 1.262  |
| **all combined** | 1.197 | 1.239  | **1.254** | 1.236  |

All policies have **0 % fall rate** under every perturbation.

Free-walk gait quality at commanded `vx = 0.4 m/s` over 10 s on
randomised terrain (the 6 s benchmark above is too short to surface the
long-horizon failure mode):

| metric | v6 | v8 | **v9** |
|---|---:|---:|---:|
| realised forward speed (m/s) | 0.317 | 0.311 | 0.30 |
| joint Δaction step-to-step | 0.067 | **0.025** | 0.04 |
| stride / period / lift scale |  — | 0.98 / 1.00 / 1.12 | 0.95 / 1.00 / 1.20 |

#### Long-horizon stuck behaviour

The same policies on an 80 s open-loop run, fixed terrain (seed 42,
4 obstacles), holding `vx = 0.4 m/s`:

| version | stuck intervals | total stuck time | longest wedge | total path |
|---|---:|---:|---:|---:|
| v6 | 0 |  0.0 s |  — | 44.7 m |
| v8 | 5 | **41.1 s** | **38.5 s** | 25.4 m |
| **v9**  | 8 | 17.2 s | **2.6 s** | 35.9 m |

v8 has the best 6 s benchmark numbers but climbs onto an obstacle
around t = 17 s and pumps its legs in place for **38 seconds** before
sliding off — this is what "smoother but stuck" looks like in practice.
v9 still bumps into things (briefly stuck 8 times) but **escapes every
encounter in under 2.6 s** thanks to the long-episode + cmd-resampling +
stuck-termination training signals.

#### Recommended policy

| policy | use it when |
|---|---|
| `walker_v6` | residual-only baseline; matches the 18-dim action API. |
| `walker_v8` | best 6 s nominal tracking; benchmark reference policy. |
| `walker_v9` | **deployment policy** — best long-horizon robustness.  |
| `walker_v10`  | proprioceptive stub-avoider; per-leg lift + swing-foot contact penalty for high-stepping over obstacles. |
| `walker_v11`  | narrow-stance variant of v10; legs tucked tight under the chassis (stance radius 70 % of the wide spider stance) for a more compact, dog-like silhouette. |

`walker_v7` was an instructive failure: overly generous gait-scale
ranges (`stride 0.5–1.4`, `period 0.7–1.3`) plus the default PPO
learning rate produced a *shuffling* gait (short strides slipping
through stance, foot-tip motion that looked frantic).  v8 clamps every
gait scale to ±15 % of nominal, gets v6's forward speed back, and
produces 2.7× smoother joint commands.  v9 trades a bit of v8's
short-horizon precision for the recovery behaviour it needs to keep
walking past obstacle interactions.

### Why Gymnasium and not ROS?

ROS is the right abstraction for **deploying** a controller on real
hardware (or for plugging the walker into a pre-built navigation stack
like Nav2 / move_base) — but it is **not** an RL training framework.
The dominant ecosystem for training MuJoCo policies (and, increasingly,
real-robot policies via sim-to-real) is the Gymnasium / Stable
Baselines3 stack used here.

If you eventually want to drive a real walker (or this simulation) from
ROS, the cleanest split is:

```
   ┌───────────────────────────┐    /cmd_vel  ┌───────────────────────┐
   │  ROS node (twist input,   │ ───────────▶ │  HexapodWalkerEnv +   │
   │  navigation stack, etc.)  │              │  trained policy       │
   └───────────────────────────┘ ◀─────────── └───────────────────────┘
                                  /odom, /imu, /joint_states
```

`HexapodWalkerEnv.set_command(vx, vy, omega)` already accepts the same
arguments as a `geometry_msgs/Twist`, so the ROS bridge is roughly:

* a `cmd_vel` subscriber → `env.set_command(...)`,
* a 50 Hz timer → `model.predict(env._obs())` → `env.step(...)`,
* publishers for `/odom` (chassis pose), `/imu/data` (chassis velocity)
  and `/joint_states` (per-joint qpos/qvel).

That bridge is intentionally **not** included here — it would otherwise
force a ROS toolchain on every developer who just wants to train a
gait.  Drop it in once you have a policy you actually like.

## Tabletop prototype

A scaled-down sibling of the full-size walker, designed for **hobby
servos** (DS3225 / MG996R class — ~$13 each) and **FDM 3D printing**.
Same hex-chassis, six-legged, alternating-tripod architecture; the
gait controller and inverse-kinematics math you write for the
prototype port unchanged to the full-size walker.

* Vehicle envelope: ~ 58 cm foot-to-foot, ~ 11 cm chassis height
* Mass: ~ 1.3 kg dry, no rider (it's tabletop sized)
* 18 actuators: generic 25 kg·cm digital servos (DS3225 / MG996R)
* Brain: Arduino Mega + 2 × PCA9685 PWM driver boards
* Power: 1 × 3S 2200 mAh LiPo + 5 V BECs
* Total BOM: **~ $200 – $440** depending on servo choice
* Print time: ~ 22 hours on an Ender 3-class printer
* Build time: ~ 4 hours

```bash
./run.sh hexapod_walker/prototype_sts3215/build_all.py      # all prototype STL bundles
./hexapod_walker/prototype_sts3215/render_prototype.sh \    # Cycles render
    --device METAL --samples 256 \
    --out renders/prototype.png
```

This writes prototype-specific STL sets under `prototype_sts3215/`, including
`stl_prototype/`, `prototype_assembly/`, `xometry_upload/`, and the
`bambu_h2d_trays/` Bambu H2D Carbon build plates.

**Validating CAD changes before printing.** The prototype ships with a
parametric validate → render → report pipeline so you can catch
geometry regressions without opening a slicer:

```bash
make -C hexapod_walker/prototype_sts3215 verify-prototype   # full verifier suite
make -C hexapod_walker/prototype_sts3215 verify-fast        # inner-loop variant (skips workspace sweep)
```

See [`prototype_sts3215/CAD_WORKFLOW.md`](../prototype_sts3215/CAD_WORKFLOW.md) for the
pipeline overview, [`prototype_sts3215/design_spec.yaml`](../prototype_sts3215/design_spec.yaml)
for the human-readable geometry contract, and
[`prototype_sts3215/CAD_AGENT_INSTRUCTIONS.md`](../prototype_sts3215/CAD_AGENT_INSTRUCTIONS.md)
for the rules an LLM coding agent should follow when editing CAD.

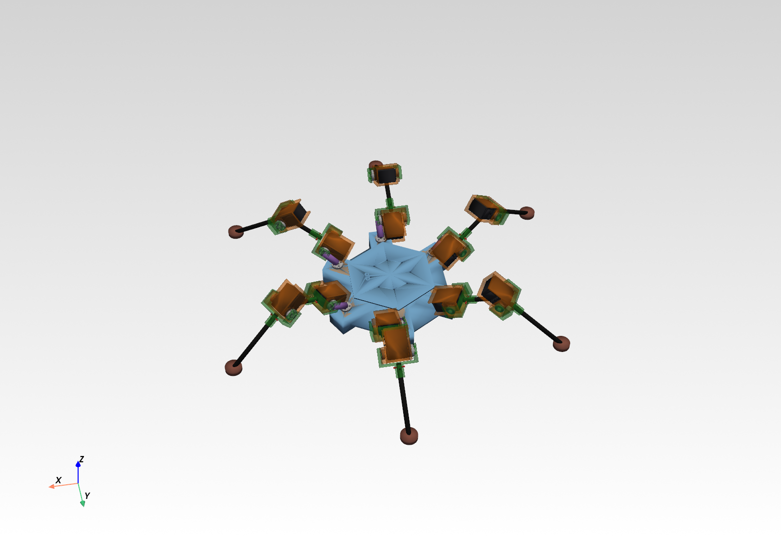
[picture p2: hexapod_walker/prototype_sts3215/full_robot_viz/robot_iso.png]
Render of the prototype hexapod walker


See [`prototype_sts3215/PROTOTYPE.md`](../prototype_sts3215/PROTOTYPE.md) for the full BOM (specific servo
recommendations, power-distribution wiring, fastener counts), print
plan, assembly sequence, starter Arduino sketch, and tuning notes.

## Status

Mechanical-design draft. **Not built or tested.** Use as a starting
point for an engineered build with proper FEA, fatigue, and thermal
review. See [`ASSEMBLY.md` § 14 (Disclaimer)](ASSEMBLY.md#14-disclaimer).
The prototype STLs are slicer-ready but also unbuilt — start with
`coxa_bracket.stl` as a cheap test print to verify your servo's exact
mounting geometry matches the assumed DS3225 / MG996R footprint
before committing to the full set.

## License

Personal exploration — no license declared yet. Open an issue if
you'd like to use any of this.

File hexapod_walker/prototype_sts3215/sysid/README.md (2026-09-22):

# sysid/ — measured hardware-to-MuJoCo calibration

Implements the sim-to-real system-identification plan
(`~/Documents/HEXAPOD_SIM_TO_REAL_SYSID_PLAN.md`): stop tuning the
simulator by intuition, measure it. Deterministic command protocols run
identically on hardware and in MuJoCo; the difference is the reality
gap, and it is scored automatically.

Builds on what already exists — `rl_move/sim/servo_model.py`
(ServoProfile + fitted parameter sets), `rl_move/sim/replay_trace.py`
(free-base episode replay), `rl_move/sim/fit_loaded_actuator.py` (the
08-10 loaded knee fit). This package adds the missing pieces:
versioned protocols, an on-robot protocol runner with per-tick
send/receive timestamps, suspended (fixed-base) replay, distribution-
style latency stats, a general per-axis fitter with held-out
validation, and the Reality Gap Report.

## Layout

```
sysid/
  protocols.py   protocol builders (step ladders, sine sweeps,
                 per-servo spread, champion traj)  -> protocols/*.json
  run_hw.py      HTTP client: run a protocol on the robot, pull the
                 trace                             -> datasets/<run>/
  gait_metrics.py  joint amplitudes / tracking / stride from any per-tick
                 CSV; --footfall adds per-leg duty, lift, swing, stride,
                 slip from foot kinematics (sim and robot alike)
  rollout_policy_csv.py  roll an exported numpy policy in the twin and
                 write a robot-format CSV for gait_metrics
  trace.py       sysid CSV schema load/write
  analyze_hysteresis.py
                 matched-dwell radial-shear loop metrics
  replay.py      suspended MuJoCo replay (trace or protocol)
  metrics.py     step / sine / latency-distribution / jitter metrics
  fit.py         per-axis actuator fit + holdout    -> sim_model_*.json
  report.py      Reality Gap Report                 -> reports/<stamp>/
  plots.py       cmd / hardware / sim overlay figures
```

Real-vs-MuJoCo VISUAL comparison (side-by-side video of the robot vs the sim
running the same commands): `rl_move/sim/replay_compare.py`
(`uv run python -m rl_move.sim.replay_compare --run <data_run_dir> --page`).
It builds on `rl_move/sim/replay_trace.py` (the per-tick divergence numbers).
Finding so far: the real robot rocks fore-aft ~3.6 deg and rolls 3-6 deg where
the sim stays near 1 deg — same joints, different body motion (compliance +
contact). Gotcha: align the real video by MOTION ONSET, not the drive-start
timestamp (per-trial stand/engage latency, and the robot clock is not the
camera clock).

Robot side (deployed with `linux_control/`): `sysid_protocol.py`
(schema + materializer, shared verbatim with this package) and
`sysid_runner.py` (25 Hz streaming executor, safety trips, CSV with
`t_send`/`t_recv` per tick), exposed as `POST /api/sysid/run`.
**The endpoint exists once `linux_control/` is redeployed to the
robot** — nothing here touches the robot until the guarded runner invokes
`run_hw.py --go` under the active campaign authority.

## Safety (non-negotiable, same rules as everywhere)

- The older `*_air_*` protocols assume: **robot suspended, feet OFF the
  ground, with live camera and a guarded runner watching.** The reviewed
  `l2_belly_rest_*` and `l5_belly_rest_*` protocols are the low-effort
  exception: leave the chassis resting normally on its belly and only clear
  the named moving leg's swept area. They do not require a chassis stand or
  every stationary foot to be airborne. The runner
  positions the legs itself: a slow (12 °/s), eased, trip-protected
  glide to the protocol's `home_deg` (bench zero for the standard
  batteries) or a champion trajectory's first row, verified to 3°
  before any segment runs.
- The one thing software cannot do is *verify the zero frame visually*:
  if `set_zero` is stale/wrong, the glide's tracking/current trips are
  the backstop (they limp and say so), but confirm zero after any
  hand-posing or reassembly.
- `run_hw.py` is a dry-run unless `--go`. Physical runs require
  `--capture-vision`: three distinct frames admit motion, and a stream that
  stops advancing remotely stops the run. Whole-body `traj` protocols
  additionally need `--force`; a traj that is discontinuous with the pose
  mid-protocol trips instead of yanking joints.
- The runner uses soft torque, per-joint current/temp trips, and a
  tracking-error trip (unexpected force = limp + descriptive error,
  suggesting a `set_zero` re-check). It always limps at the end.
- `uv run python -m sysid.run_hw --abort` = emergency stop (`/api/rl/stop`).

## Workflow (maps to the plan's phases)

```sh
cd hexapod_walker/prototype_sts3215      # uv run finds the repo-root .venv from here

# Phase 0 — build the versioned protocol files (already in git;
# rebuild only to change repeats/amps — the hash changes with content)
uv run python -m sysid.protocols build

# Preview any protocol in sim before touching hardware
uv run python -m sysid.replay --protocol sysid/protocols/steps_air_v1.json \
    --servo-params loaded --plot

# Low-effort L2/L5 repeatability check (normal belly rest; no stand):
uv run python -m sysid.run_hw \
  --protocol sysid/protocols/l2_belly_rest_radial_shear_hysteresis_repeat6_v1.json \
  --capture-vision --go --force
uv run python -m sysid.run_hw \
  --protocol sysid/protocols/l5_belly_rest_radial_shear_hysteresis_repeat6_v1.json \
  --capture-vision --go --force

# Phase 1+2 — older guarded bench battery (robot suspended):
uv run python -m sysid.run_hw --protocol sysid/protocols/steps_air_v1.json \
  --capture-vision --go
uv run python -m sysid.run_hw --protocol sysid/protocols/sines_air_v1.json \
  --capture-vision --go
# Phase 6 — every servo, reduced battery:
uv run python -m sysid.run_hw --protocol sysid/protocols/servo_spread_v1.json \
  --capture-vision --go

# First overlay + gap numbers (also covers Phase 2: latency/jitter
# DISTRIBUTIONS from the per-tick t_send/t_recv and step onsets)
uv run python -m sysid.report --csv sysid/datasets/<run>/*.csv \
    --servo-params air loaded

# Accepted radial-shear metric (leg/profile inferred from the dataset)
uv run python -m sysid.analyze_hysteresis sysid/datasets/<run>/*.csv

# Phase 3 — fit actuator/timing params (holdout: ±10° steps, 0.5 Hz)
uv run python -m sysid.fit --csv sysid/datasets/<run>/*.csv \
    --out rl_move/sim/sim_model_sysid.json
# use in training/eval: --cfg-set bus.servo_params=<path to json>

# Phase 8 — suspended champion replay (Test A):
uv run python -m sysid.protocols champion --csv <rl_*.csv or sim eval csv>
uv run python -m sysid.run_hw --protocol sysid/protocols/champion_*.json \
    --capture-vision --go --force
uv run python -m sysid.report --csv sysid/datasets/champion_*/*.csv \
    --servo-params sim_model_sysid.json
```

Decision tree after Test A (plan Phase 8): suspended mismatch →
actuator/timing (iterate here); suspended match → move to loaded/
contact work, for which `fit_loaded_actuator.py` and
`replay_trace.py` (free-base, on ground) are the existing tools.

## Conventions

- A protocol file's SHA-256 content hash identifies the experiment;
  the runner embeds the full protocol in every trace summary, so every
  dataset is self-describing and reproducible.
- Raw hardware traces in `datasets/` are append-only; never edit them.
- Fit quality is judged on the HELD-OUT set and full-trace replay RMSE
  (`fit.py` prints fitted-vs-base for both) — training-fit alone
  counts for nothing.
- Phases 4/5/7 (loaded actuator, current↔torque, contact) come after
  suspended agreement; fit contact only with actuator params frozen.

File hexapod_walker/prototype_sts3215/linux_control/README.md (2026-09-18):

# STS3215 linux control (Uno Q web + Xbox)

Drive the Feetech STS3215 hexapod from a browser on your laptop, or with an
Xbox controller.  The Python drive loop runs on the **Arduino Uno Q** Linux
side.  Prefer the **MCU Feetech bridge** (STM32 owns D0/D1 → FE-URT UART at
1 Mbps); fall back to a USB URT-2 / Waveshare adapter if needed.  See
`../firmware/WIRING.md` and `mcu_feetech_bus.py`.

```
Laptop browser / Xbox ──HTTPS──▶ Uno Q web_drive.py
                                      │
                                      ▼
                               DriveController + TripodGait
                                      │
                    ┌─────────────────┴─────────────────┐
                    ▼                                   ▼
            McuFeetechBus                         FeetechBus (USB)
            /dev/ttyHS1 @921600                   /dev/ttyUSB* @1Mbps
                    │                                   │
                    ▼                                   │
            feetech_bridge (MCU)                        │
            FE-URT UART @1Mbps                          │
                    └─────────────────┬─────────────────┘
                                      ▼
                               STS3215 daisy chain (IDs 2–19)
```

## Autostart on the Uno Q

`web_drive` is meant to come up on every boot via systemd:

```bash
# on the board (or via ssh / adb shell):
cd ~/hexapod_sts/linux_control/systemd
chmod +x install_autostart.sh
./install_autostart.sh          # needs sudo (password: arduino)
```

Then: `systemctl status hexapod-web`, `journalctl -u hexapod-web -f`.
After a power cycle the UI should answer on `:8080` / `:8443` without a manual start.

The service's privileged `ExecStartPre` runs `systemd/cpu_performance.sh` to
select the `performance` CPU governor before starting the web process as
`arduino`. On the measured Uno Q, `/sys/devices/system/cpu/cpufreq/policy0`
controls all four cores, with a 2.016 GHz maximum. The September 5 CPU-only
cadence comparison showed `schedutil` dropping to 614–864 MHz during a loop
that slept for UART I/O; the same CPU work grew from about 2.7 ms to 6.5 ms.
Even a warmed loop downclocked again. The helper changes only the governor,
retaining the kernel's frequency limits and thermal protection. It checks
availability and readback, and logs `hexapod-cpu: WARNING` without blocking
startup if CPU tuning is unsupported or fails. Both normal deploy transports
already ship the helper and reload the updated unit.

Verify with `cat /sys/devices/system/cpu/cpufreq/policy0/scaling_governor`
and `journalctl -u hexapod-web -b --no-pager`. This setting remains active
after the service stops. For a temporary idle comparison, write `schedutil`
back with `echo schedutil | sudo tee /sys/devices/system/cpu/cpufreq/policy0/scaling_governor`;
the next service start restores `performance`. Governor selection changes
CPU scheduling capacity, not the trained policy rate or motion limits.

The installer now checks both listeners:

```bash
curl -s http://127.0.0.1:8080/api/ping
curl -sk https://127.0.0.1:8443/api/ping
```

The HTTPS listener auto-generates a self-signed certificate when no cert is
configured. For a browser-trusted certificate, provide both environment
variables in a systemd drop-in and restart `hexapod-web`:

```ini
[Service]
Environment=HEXAPOD_TLS_CERT_FILE=/home/arduino/.hexapod_sts_cert.pem
Environment=HEXAPOD_TLS_KEY_FILE=/home/arduino/.hexapod_sts_key.pem
```

Safari will still warn on the default self-signed cert until macOS trusts it.
The usual fixes are either:

- add the generated cert to macOS Keychain Access and set it to Always Trust;
- generate a cert with a locally trusted CA such as `mkcert`, including the
  names you actually open (`localhost`, `127.0.0.1`, `hexapod.local`, and the
  board IP), then copy that cert/key to the paths above.

### Boot chain (2026-08-07)

The STM32 (feetech_bridge + TFT) does **not** auto-run its sketch after an
SoC reboot — stock images rely on `arduino-router` bringing it up ~80 s into
boot. Two things make boot fast and deterministic instead:

- **`hexapod-mcu-ready.service`** (installed by `install_autostart.sh`) runs
  right after `local-fs.target` and hard-boots the MCU over SWD
  (`systemd/mcu_boot.sh` → `remoteocd upload -f mcu_reset.cfg`). The panel
  splash + "linux Ns" boot ticker appear a few seconds after power.
- **`hexapod-web.service`** no longer waits for `network-online` (it binds
  `0.0.0.0`), and the bus constructor retries HELLO in-process — including
  the same SWD reset as a rescue — instead of exiting into a systemd
  restart loop.

Result: web up ~30 s after power (was 60 s+, or wedged forever if the port
claim raced `arduino-router`'s MCU bring-up). If the bridge ever goes
silent, `uv run python -c "import mcu_feetech_bus as m; m.mcu_reset()"` reboots
the MCU without touching servo power.

## Timestamped command / log stream → laptop

Every drive command, HTTP POST, MCU bridge command (non-chatty), print, and
motion-telemetry tick is written as JSONL on the robot and UDP-streamed to
any laptop running the receiver — **no IP to configure**. The robot
broadcasts on the LAN and learns your laptop from beacons on port 9378.

```bash
# on the laptop — leave running while you operate the robot
cd hexapod_walker/prototype_sts3215/linux_control
uv run python receive_robot_logs.py
# backup path if UDP is firewalled:
uv run python receive_robot_logs.py --ssh arduino@hexapod.local
```

Robot side: `logs/events.jsonl`. Optional override only if you need it:
`HEXAPOD_LOG_HOST=<ip>` in the systemd unit.

### Who commanded what

`GET /api/commands` (also `logs/commands.jsonl` on the board) is the
attributed journal of state-changing POSTs: `controller` is `robotlab`,
`mac-hub via <browser address>` (a click on the `:8898` hub page, which also
prints one `[hub->robot] POST ...` line per relayed command into the hub log,
`make web-8898-logs`), `script` (curl / plain urllib), or `browser@<ip>`.
Scripts can name themselves with an `X-Hexapod-Controller` header.

### Error log (website refusals / failures)

Every error the web UI shows — API `ok:false` / `"error"` responses
(e.g. `refused sit zero: …`), HTTP 4xx/5xx, and async demo/worker
errors that only surface via status polling — is logged with
`level="error"`: it lands in `events.jsonl`, is mirrored to a
dedicated `logs/errors.jsonl`, and streams over the same UDP fanout.
Identical repeats (a poll loop hitting the same failure) are deduped
to once per 10 s. Browse the recent ones without SSH:
`GET /api/errors?n=100`.

### Toggleable full telemetry + foot-contact observer

The command/error event log above is always on. A separate high-rate JSONL
recorder can be started or stopped while another web test is already running:

```bash
# Start a named session. 50 Hz is the default and the recommended first run.
curl -s -X POST http://hexapod.local:8080/api/telemetry \
  -H 'Content-Type: application/json' \
  -d '{"action":"start","label":"floor-gait-1","max_hz":50}'

# Optional timestamped annotation while it runs.
curl -s -X POST http://hexapod.local:8080/api/telemetry \
  -H 'Content-Type: application/json' \
  -d '{"action":"mark","label":"front-left-dragged"}'

# Status is in-memory only; it causes no bus traffic.
curl -s http://hexapod.local:8080/api/telemetry

# After POSTing a marker, poll its exact flush acknowledgement by marker_id.
curl -s 'http://hexapod.local:8080/api/telemetry?marker_id=<marker_id>'

curl -s -X POST http://hexapod.local:8080/api/telemetry \
  -H 'Content-Type: application/json' -d '{"action":"stop"}'
```

Sessions are saved as `logs/telemetry_<UTC>_<label>.jsonl`, appear in
`GET /api/logs`, and are never automatically pruned. Each line contains all
state that the active operation already made available: commanded joints,
encoder position/speed, full current/load/voltage/temperature feedback, IMU,
or power summary as applicable. Tests that only write commands produce
command-only records; the recorder deliberately does not insert a feedback
read behind their backs.

Each durably flushed (`fsync`) marker has a bounded, per-session `marker_ack`
entry containing its exact rotated-file `path`, `paths` snapshot, sequence and
writer count, plus the marker-bound queue/communication/capture loss checkpoint.
Querying by ID keeps concurrent marker clients from mistaking a later
`flushed_marker` for their own acknowledgement.

This timing isolation is structural: the bus callback only attempts a bounded
in-memory enqueue. JSON encoding, the five-reading contact filter, and file
writes run on a background thread. High-rate command/snapshot records are
capped at `max_hz` (1–100 Hz); richer full-feedback, IMU, power, and marker
records are always accepted when observed. If storage cannot keep up, the
queue drops samples instead of blocking motion. Check `rate_limited` for
intentional sampling and `queue_dropped`/`write_error` for actual loss.

On stream-capable MCU firmware, a due sample on an ordinary SyncWrite uses the
existing combined `S` write+snapshot command instead of `W`. The servo command
and cached encoder/speed/IMU reply share one transaction—there is no second
polling transaction or competing reader. The reply is longer than `W`'s `OK`,
so `max_hz` also bounds that transport overhead. This is the same combined path
used by the 100 Hz RL controller; the recorder defaults to 50 Hz.

Set `HEXAPOD_TELEMETRY_AUTO=1` to start an `auto` session with the web service,
and optionally set `HEXAPOD_TELEMETRY_HZ` or `HEXAPOD_TELEMETRY_QUEUE`. Manual
start is the safer default because persistent logs consume disk indefinitely.

The six `contact` probabilities in the records are from the simulation-trained
observer documented in `../rl_move/CONTACT_PREDICTOR_EVAL.md`. They are for
physical validation only: `observer_only=true` and `gait_gating=false` are
written into both status and every estimate. Nothing in this recorder changes
a gait or declares a leg safe to unload.

### Phone-video diagnosis

When a run fails, save the phone video and generate timestamped stills plus a
contact sheet before guessing from memory:

```bash
make robot-video VIDEO=/Users/lukas/Downloads/IMG_3613.MOV
# optional: exact timestamps and a fractional crop around the robot
make robot-video VIDEO=/path/run.mov TIMES=0,8,16,24,32 CROP=0,0.33,1,0.98
```

The helper lives at `linux_control/video_contact_sheet.py` and writes under
`artifacts/video_frames/...`.

For the AprilTag + red-boot live phone overlay, short-occlusion tracking, an
advisory zero-pose report, and optional read-only encoder cross-check, see
[`hexapod-tracker/docs/HOUSING_POSE.md`](../hexapod-tracker/docs/HOUSING_POSE.md).
The shortest live command is:

```bash
uv run python linux_control/track_apriltags.py \
  hexapod-tracker/configs/apriltag_pose_config_20260831.json \
  --camera 0 --preview --robot-url http://hexapod.local:8080 \
  --pose-output phone_checkup.jsonl \
  --summary-output phone_checkup_summary.json
```

The tracker only reads `GET /api/feedback`; it cannot send motor commands or
rewrite zero. Use the overlay to hand-adjust and diagnose the pose.

The implementation, configs, tests, and camera UI live in the
[`hexapod-tracker`](../hexapod-tracker) submodule. The historical
`linux_control` commands are compatibility adapters for existing workflows.

Cameras are served by the tracker's multi-camera server on `:8766`, run as a
launchd job by `hexapod-tracker/tools/camera_service.sh` (see
[`hexapod-tracker/docs/LLM_HANDOFF.md`](../hexapod-tracker/docs/LLM_HANDOFF.md)).
It discovers the attached cameras at every launch, pins each slot by its
AVFoundation stable id, keeps one camera per USB host controller, and
relaunches itself when the rig changes. Robot Lab, the sysid runner and the
calibration programs read frames from it over HTTP; nothing else opens a
camera. The hub on `:8898` no longer has a vision page or camera worker.

One trap when several cameras are attached, documented with measurements
in [`hexapod-tracker/docs/LLM_HANDOFF.md`](../hexapod-tracker/docs/LLM_HANDOFF.md):

- **One USB 2.0 bus carries about two full-resolution OV9281 streams.** These
  cameras have no compressed mode, so several on a single hub will starve.
  Spread them across separate USB host controllers; a hub adds no bandwidth.
  Torn, blocky frames usually mean two processes opened the same camera rather
  than a saturated bus.

## Fast test / deploy loop

For repeated camera/telemetry snapshots, bounded passive recording, and offline
recovery-trial summaries, use [the observation helpers](ROBOT_OBSERVE.md):
`uv run python -m linux_control.robot_observe --help`, or `hex_observe` after
sourcing the dev-loop script below. These helpers only observe; they never change torque.

For UI and controller edits, use the local helper instead of retyping the
whole cautious sequence. These commands do not move the robot; only
`hex_deploy` restarts the web service.

```bash
# from prototype_sts3215/
make robot-check       # syntax + web JS + git diff hygiene; no robot access
make robot-unit-check  # robot-check + fake-bus/off-robot tests
make robot-resolve     # refresh/print cached robot IP for hexapod.local
make robot-status      # read-only /api/ping + compact /api/robot summary
make robot-deploy      # robot-check + SSH deploy + remote compile + status
```

The same helpers are available as shell functions:

```bash
source linux_control/dev_loop.sh
hex_check
hex_unit_check
hex_resolve
hex_status
hex_deploy
```

Useful overrides:

```bash
HEXAPOD_HOST=http://hexapod.local:8080
HEXAPOD_SSH=arduino@hexapod.local
HEXAPOD_SSH_HOSTKEY_ALIAS=hexapod.local
```

If `hexapod.local` resolution is flaky, do not commit an IP address. Resolve
the current address once and let the helper cache it in `~/.hexapod/last_ip`.
`make robot-status`, `make robot-deploy`, `make robot-deploy-fast`, and remote
compile prefer the cached raw IP and only fall back to mDNS when the cache is
missing or stale:

```bash
make robot-resolve
make robot-status
make robot-deploy
```

There is also an explicit-path commit helper, intended to avoid
accidentally staging unrelated work from another process:

```bash
hex_commit_push "Add safer robot telemetry" \
  linux_control/web_drive.py linux_control/webui/app.js
```

## Replacing a servo

A new STS3215 answers on bus ID 1 and keeps its factory zero, so after a swap
the robot shows 17 named servos plus `ID1` in `/api/status` and every stand
refuses with `no encoder reading from <joint>`. With the robot limp and the
legs lying straight out (the STEP keyframe-0 pose, every joint ~0):

```bash
# from prototype_sts3215/; HEXAPOD_HOST=http://hexapod2.local:8080 for the other robot
uv run python linux_control/motor_swap.py status              # empty slot? ID 1 present? flat-pose outliers
uv run python linux_control/motor_swap.py assign              # ID 1 -> the empty slot (POST /api/setup/scan + assign)
uv run python linux_control/motor_swap.py zero --ids 4        # middle-calibrate where it sits (POST /api/set_zero)
uv run python linux_control/motor_swap.py check --joint 2 \
    --stream http://<camera-host>:8766/raw-stream/1.mjpg     # gentle wiggle, then +-15 deg with the camera watching
```

`assign` and `zero` are the only EEPROM writes and both refuse while armed.
The registry the robot saves to is `~/.local/share/hexapod/motor_setup_registry.json`
on the board. Then stand normally (`POST /api/rl/stand`) and compare the new
joint's `load_pct`/`current_a` in `/api/status` with its five siblings before
walking. Done this way on hexapod.local 2026-09-18 (L0 knee, 163 deg -> 0).

## Comparing gaits (repeatable)

`linux_control/gait_sweep.py` is the one command for "how do the gaits do on
this robot". It refuses to move until the top camera's saved floor fit still
matches the anchors, records the top camera for the whole sweep, walks each
gait for N seconds per round (direction alternating so the robot stays under
the camera), retries a start that dies on a stale MCU snapshot, aborts under
10.8 V on the servo bus, and lowers + limps the robot at the end. Then it
writes `analysis.json`, `TABLE.md` and the Lab scorecard `gaits.json`.

```bash
# from prototype_sts3215/; the camera CLI is the tracker checkout's (HEXAPOD_CAMERAS_BIN to override)
~/hexapod-tracker/.venv/bin/hexapod-cameras check --role top      # bumped camera? -> calibrate floor --role top
uv run python linux_control/gait_sweep.py run --host http://hexapod2.local:8080 --name hexapod2 \
    --chassis-tag 119 --exposure-s 6 --rounds 2 --out ~/.hexapod/lab_runs/$(date -u +%Y%m%d_%H%M)_gaits_hexapod2
uv run python linux_control/gait_sweep.py table ~/.hexapod/lab_runs/2026*_gaits_*      # one row per robot x gait
"$HOME/Library/Application Support/Hexapod Lab/venv/bin/hexapod-lab2" import --robot hexapod2 \
    --title ... --why ... --found ... --gaits <run>/gaits.json <run>                    # file it in the catalog
```

Speed and heading change come from the chassis lid tag's floor-referenced
track (`--chassis-tag`; hexapod2 = 119). Without it the best-covered lid tag is
used and the row says so; lid tags swing with the legs and vanish under the
overhead cable, so treat those speeds as rough. An arm is `inconclusive` unless
two exposures ran for 70 % of the planned time; hexapod1's IMU-stale trips
(2026-09-18) produce exactly that. Both robots need to be inside the top
camera's tag area; the ELP side camera is video only.

## Calibration checkup / geometry sweep

The Web UI **Checkup** route runs, in order: safe zero, IMU rest/bias,
ground-contact plant search, per-leg dimension sweep, geometry plausibility,
quad IMU body-frame map, IMU-frame validation, stability-margin probe,
mass-shift response, traction/slip probe, return-to-zero, a proprioception
consistency score, optional camera witness metadata, bus error-rate checks
while still and during the motion phases, bus/power health, actuator snapshot,
then one calibration report.  The
proprioception phase is read-only after return-to-zero: it compares the expected
zero pose with live servo encoders/current/voltage/temperature and flags large
command-vs-feedback errors.  It cannot prove where the feet moved in the room;
synced camera/video is the separate witness needed for slip and body
translation.  The moving checks are deliberately less conservative than older
runs: weak geometry, small IMU-frame samples, and recoverable slip-probe guards
are recorded as issues/warnings while the checkup continues to collect
independent evidence. Operator stop/E-stop, hard command failure, high current,
or sustained large tilt still stop motion. The stability-margin phase uses small
reversible stance biases in four directions and reports a lower-bound usable
tilt, not a fall angle. The mass-shift phase lifts small limb groups and records
steady pitch/roll response, which is the first useful proxy for center-of-mass
and limb-mass mismatch in MuJoCo. The standard checkup traction phase uses two
repeated planted shear trials at several small yaw amplitudes and reports
min/max ranges; the more aggressive per-leg loaded-vs-hover drag remains the
explicit standalone slip probe. The dimension sweep
keeps five feet planted and probes several same-floor hip/knee contact poses
with the sixth leg.  Treat it as a contact-height consistency diagnostic:
vertical floor contacts alone do **not** identify absolute femur/tibia lengths
because link lengths and body height are scale-ambiguous without an independent
height/vision measurement.  The report therefore keeps configured/manual link
lengths as the dimension source and uses the sweep for per-leg height residuals,
zero-offset hints, and mismatch warnings.  Boot edges, footpad angle, floor
compliance, and servo lag can all make first contact differ from the ideal tibia
endpoint.  The sweep records weak first-contact brushes separately from firm
loaded contacts and backs the probe leg off immediately after a contact hint;
continuing to push mostly measures boot/chassis flex.  When the operator
measures knee-to-boot-tip, use the boot-radius contact model
`height = (tip_mm - boot_radius_mm) * sin(theta) + boot_radius_mm`, not a
pin-foot line to the tip.  Coxa length and chassis width remain nominal/manual
because vertical floor contacts do not observe horizontal geometry.

Deploys paint a temporary TFT **DEPLOYING** banner while the web service is
stopped.  After `/api/ping` succeeds, the deploy scripts now call
`POST /api/tft/ready` to do one normal screen repaint and clear that banner
without enabling the continuous TFT status loop.  The route skips if a motion or
calibration already owns the MCU link.

Raw sweep samples are saved on the robot as
`linux_control/logs/geometry_sweep_*.json` and copied into
`calibration_report_*.json` under `geometry.contact_sweep`.  Off-robot math
coverage lives in `linux_control/test_geometry_sweep_fit.py` and is included
in `make robot-unit-check`; it does not touch hardware.

Hand measurements live separately from the moving checkup:
`GET/POST /api/geometry/manual` reads or writes
`linux_control/logs/geometry_manual.json` with `hip_pitch_height_mm`,
`hip_center_radius_mm`, `femur_mm`, and `tibia_mm`.  The report shows these
as operator measurements, uses manual hip height for MuJoCo height hints, and
keeps FK-derived height plus current-vs-absolute knee convention comparisons
visible as consistency checks.  If the contact/FK height disagrees with the
operator measurement, the sweep is marked `manual_geometry_mismatch` and is not
used as a dimension source.

Touchdown-zero hints are separate from Feetech middle calibration:
`POST /api/measure/touchdown_zero` low-torque taps requested legs near the
geometry-predicted hip/knee floor contact angles, logs raw samples, and saves
`linux_control/logs/touchdown_zero.json` only when every requested leg/axis
finds contact.  `GET /api/touchdown_zero` reads the latest saved hints.  The
saved `encoder_zero_error_deg` values are software compensation hints; this
route never rewrites servo EEPROM zero or calls `/api/set_zero`.

Measured-geometry decision, 2026-08-21: the old 128 mm tibia/contact length
was retired.  MuJoCo, the gait IK, and the checkup geometry now use
`femur_mm=90.0`, `tibia_mm=150.0` (knee axis to boot apex/contact tip), and
`boot_diameter_mm=9.0`.  The nominal hip-center radius remains
`200/2 + 12.5 = 112.5 mm`, close to the operator's about-114 mm measurement;
keep using `/api/geometry/manual` for measured height/radius annotations.  For
future geometry changes, update motion constants only after the measurements,
contact sweep residuals, and MuJoCo behavior agree.

### RL episode traces (automatic)

Every RL stand / lower / walk run additionally writes per-tick telemetry
on the robot: `logs/rl_<mode>_<stamp>.csv` (at the policy's real 25/50/100 Hz
cadence — attitude, raw calibrated accel + gyro, goal refs, measured +
commanded q, raw action, per-servo current) and a
matching `_summary.json` (params + result), with `rl_episode` start/end
markers in `events.jsonl`. Full column list and analysis notes:
`../rl_move/API.md` § "RL episode logging". Pull with
`scp arduino@hexapod.local:hexapod_sts/linux_control/logs/rl_*.csv`.

## Quick start (Uno Q over USB adb)

1. Plug the Uno Q into the Mac with USB-C (adb).
2. Ensure the FE-URT is on the MCU UART path (preferred) **or** on USB-C OTG.
3. From the Mac:

```bash
cd hexapod_walker/prototype_sts3215/linux_control
chmod +x deploy_adb.sh
./deploy_adb.sh            # pushes code; --dry-run if no bus yet
./deploy_adb.sh --bus       # when you want a live bus bring-up
```

4. Open:
   - UI / keyboard / on-screen sticks: **http://127.0.0.1:8080**
   - Xbox on the **Mac** (browser Gamepad API): **https://127.0.0.1:8443**  
     (accept the self-signed cert warning once, or trust/configure a cert as
     described in "Autostart on the Uno Q")

`deploy_adb.sh` sets `adb forward` for 8080 and 8443 automatically.

### Tabs

| Tab | What it does |
|---|---|
| **Drive** | Walk teleop (sticks / keyboard / Xbox) |
| **Motors** | Live bus status (ID, load, current, alarms), wiggle, limp, go-zero |
| **Demos** | `inplace_demos` suite (shimmy, rise, walk, …) |
| **Calibrate** | Plant height / joint tests |
| **Debug** | Per-joint jog / sequential wiggle test |

### Controls

| Input | Action |
|---|---|
| Enable servos | ARM (torque on; nothing moves yet) |
| Stand | planted stand (default hip **+19°**, knee **+28°**, or learned plant) |
| Check ready | read-only readiness check inside Manual Drive: servos, IMU/tilt, and walk-start pose |
| Left stick / WASD | manual drive with the selected Drive gait |
| Turn stick / Q·E | yaw rate |
| Sit & power off | STEP lower, then limp |
| EMERGENCY STOP | limp immediately |
| Xbox on Drive | left stick walk · right stick turn · D-pad up/down=stand/lower · B=stop gait/demo |
| Xbox chords | hold LB/LT/RB/RT then tap X/Y/A/B → 16 demos |

The Drive tab is a laptop-friendly manual-drive cockpit: gait picker on the
left, all stand/check/drive/stop/sit controls on the right. It defaults to the
Central Pattern Generator (CPG) tetrapod, loaded with
`CPGLOAD cpg_controller_robust120_yawtrim.json` and selected as `GAIT 6`.
Its comparison drawer also exposes no-slip tripod (`GAIT 1`), no-slip ripple
(`GAIT 2`), no-slip wave (`GAIT 3`), smooth no-slip clamp-fit tripod
(`GAIT 7`), middle-up quad crawl (`GAIT 8`), and the tunable high-step tripod
(`GAIT 0`). GAIT 0 is the shared preset used by both the real robot page and
the MuJoCo web session; its editable fields map to
`GTUNE period=... lift=... stride=... ramp=... vx=... vy=... omega=...`. Apply
tuning only while stopped, then start the next walk.

## Onboard Bluetooth Xbox

Pair once on the board (`bluetoothctl`), then:

```bash
adb shell
cd ~/hexapod_sts/linux_control
PYTHONPATH=vendor:../motor_setup:.:.. uv run python xbox_drive.py --list
PYTHONPATH=vendor:../motor_setup:.:.. uv run python xbox_drive.py
```

(User is already in the `input` group on stock Uno Q images.)

## Wi‑Fi (optional)

Right now the board’s `wlan0` is down, so the Mac reaches the UI through
**adb port-forward**.  To use the LAN instead:

```bash
adb shell
nmcli device wifi connect 'YOUR_SSID' password 'YOUR_PASS'
ip -4 addr show wlan0
```

Then open `http://<board-ip>:8080` (and `https://…:8443` for gamepad).

## Files

| File | Role |
|---|---|
| `web_drive.py` | HTTPS/HTTP server + bench glue (serves `webui/`) |
| `bench_api.py` | bench JSON API dispatcher — the route groups live in `api/` |
| `api/` | BenchAPI route-group mixins (`common` header + core/demos/zero/calibrate/rl/standup/measure) |
| `webui/` | the browser UI — HTML/CSS/JS + favicon (see `webui/README.md`) |
| `drive_controller.py` | command parser + 50 Hz gait → bus |
| `bus_bench.py` | measure feedback/tick rates over the bus (read-only) |
| `tripod_gait.py` | open-loop tripod (stdlib only; plant-synced) |
| `mcu_feetech_bus.py` | preferred MCU bridge client |
| `xbox_drive.py` | Bluetooth pad on the board |
| `vendor/` | offline `pyserial` + `scservo_sdk` |
| `deploy_adb.sh` | push + start over USB |

## Safety

- Boots **disarmed** (torque off).
- Never use Feetech `speed=0` (that means max) — the driver coerces holds.
- First walks: keep max speed low (~40 mm/s), clear floor, be ready on E-stop.

## RL / sim

Learning stack lives in `../../sts/` (MuJoCo + residual PPO).  Strategy notes:
`RL_PLAN.md` in https://github.com/lukas/hexapod-orchestrator (single RL plan doc; sim↔real facts in its Appendix A).

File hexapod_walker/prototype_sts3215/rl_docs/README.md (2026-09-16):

# rl_docs — index (read this first, then only what you need)

Small, single-purpose files so no one (human or LLM) has to dig
through a 5,000-line log to answer a question. Each file says what
it is for; keep them SHORT when you edit them.

The two walking goals, each demonstrated in sim and physically, are defined
in `RL_GOALS.md` of https://github.com/lukas/hexapod-orchestrator (the
autonomous orchestrator, its rules and its state live there): progress
by any effective means, alongside walking learned entirely through RL with
no demonstrations. Eight method tracks live in
`orchestrator/tracks.json` (hexapod-orchestrator): `joystick`, `amp`, `cpg`, `standwalk`,
`assistfade`, `todaypolicy`, `speed` serve `any_means`; `walkcurr` serves
`rl_only`.
Method PASS is not parent-goal completion. Superseded docs were retired 2026-09-14 (git history before that commit).

| File | What it answers | When to read |
|---|---|---|
| `RL_GOALS.md` (hexapod-orchestrator root) | The two goals, sim demos, physical evidence, demonstration boundary and priorities | Every cycle, first |
| `CURRENT_TRUTHS.md` (orchestrator state) | Accepted facts and run verdicts; RL_GOALS owns purpose/priorities | Every cycle |
| `RL_PLAN.md` (hexapod-orchestrator root) | The plan for physical delivery and demonstration-free research in parallel | Every cycle |
| `STATUS.md` (hexapod-orchestrator root) | Operator-facing digest: how it's going, what's waiting | Catching up; after any story-changing verdict (update it!) |
| `tracks/<track>/STATUS.md` | Per-track Goal/Now/Next journals: orchestrator STATE (`.state/rl_docs/tracks/` in lukas/hexapod-orchestrator); design notes and bundles stay here | Working that track |
| `AMP_LOCOMOTION.md` | The AMP method charter within any_means (incl. repo adaptations — no Isaac Lab) | Before any amp-track design decision |
| `DOWNLOAD_ANSWER.md` | The current deployable answer + gate evidence | When a verdict might change what we'd put on the robot |
| `HYBRID_DEMO.md` | How to compose stand/walk/lower controllers with explicit states and compare transfer-shaped MuJoCo demos | When judging policy+state bundles for robot transfer |
| `DEPLOYABLE_POLICY_EXPORT.md` | W&B/SB3 checkpoint to portable MLP or persistent dual-GRU JSON; exact obs-75/81 layouts and parity checks | Exporting or reviewing a model for MuJoCo/robot runtime |
| `HARDWARE.md` | Real-robot evidence, sim2real findings | When a decision hinges on real-world data |
| `../docs/GAIT_SIM_VS_HARDWARE_2026-09-11.md` | Every gait run on hexapod 1 and 2 vs its MuJoCo version: speed, stride Hz, amplitude, tracking, tilt; per-row sim model family | Before claiming anything about sim-to-real transfer of a gait; pair with `sysid/gait_metrics.py` |
| `SIM.md` | What the physics sim models, actuator numbers, DR coverage | Before touching sim params/DR or judging sim-vs-real gaps |
| `REWARD.md` | Every reward term: cfg key, default, what it pays/charges, income-gate design rules | Before adding/changing any reward term |
| `EVALS.md` | Every eval metric: `SCORE/*` names, `eval/*` details, harnesses, caveats | Reading a W&B page or wiring a new metric |
| `GAIT.md` | Anti-paddle gait quality: lift-and-place metrics, known exploits | Judging walking video; designing gait rewards |
| `FAST_PROFILE.md` | Raised servo profile facts + command-tracking prep | Fast-gait arms on the joystick track |
| `COMPLIANCE.md` | Structural-compliance measurement + sim hook | Sim-fidelity questions |
| `EXPERIMENT_LOGS.md` | Per-run `logs/experiments/<run>/` convention (dig-ins) | When digging into a run |
| `WANDB.md` | How W&B is wired: project/creds, ops.sh readers, gotchas | First time touching W&B or on auth failure |
| `RESEARCH_RULES.md` + `RUN_INTERPRETATION_RULES.md` (hexapod-orchestrator root) | How to design, launch, continue, and judge runs (incl. the 08-21 reward/eval ruling) | Before launch/triage |
| `orchestrator/guardrails.yaml` (hexapod-orchestrator) | Hard limits you must obey | Every cycle |

Standing rule: if you had to FIGURE OUT a command (it failed, was
slow, or took several tries) and then got it right, promote it —
add an `ops.sh` subcommand or a snippet to `COMMANDS.md` in lukas/hexapod-orchestrator, in the
same cycle, and keep this index accurate. The next agent should
never have to rediscover it.

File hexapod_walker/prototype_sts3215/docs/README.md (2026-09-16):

# STS3215 design documents

Mechanical design, CAD, BOM, printing and BuildViz moved to their own repo on
2026-09-15: https://github.com/lukas/hexapod-cad (`PROTOTYPE.md` there is the
build entry point). This directory keeps the robot-side notes that code or the
orchestrator (https://github.com/lukas/hexapod-orchestrator) still reference.

- [`../JOINT_COORDINATES.md`](../JOINT_COORDINATES.md) — joint signs, frames,
  and pose conventions shared by CAD, simulation, and control; the executable
  form is `hexapod_core/joint_frame.py`.
- Dated `*_2026-09-*.md` notes here are referenced from tracks or code; new
  journal entries go to the orchestrator's state directory (`RL_LOG.md`,
  `CURRENT_TRUTHS.md`, `rl_docs/meta/` in lukas/hexapod-orchestrator), not here.

## Other work areas

- [`../rl_docs/README.md`](../rl_docs/README.md) owns RL campaign
  documentation.
- [`../linux_control/README.md`](../linux_control/README.md) owns robot-control
  and deployment documentation.
- [`../hexapod-tracker/README.md`](../hexapod-tracker/README.md) owns camera,
  AprilTag, and perception documentation in its standalone submodule.
- Frozen handoffs and historical status snapshots were retired from the tree
  2026-09-14; use git history. Do not treat archived status files as current truth.

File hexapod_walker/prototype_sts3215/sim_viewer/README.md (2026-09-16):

# sim_viewer — running the RL champions in MuJoCo on the Mac

Everything needed to watch / drive the trained policies locally.
Written 2026-08-09 after re-deriving all of this one too many times.

## TL;DR

```sh
cd hexapod_walker/prototype_sts3215
make web-8898-start     # local hub: HTTPS :8443 (gamepad) + HTTP :8898
sim_viewer/sim_play.sh     # ← the one to use: stand up AND walk, one window
sim_viewer/sim_web.sh      # same web UI as the robot, routed to MuJoCo
sim_viewer/sim_stand.sh    # stance champion alone (mujoco.viewer)
sim_viewer/sim_walk.sh     # walk champion alone (cv2 drive window)
sim_viewer/sim_quad.sh     # tip-back QUAD walk playground (scripted, no RL)
```

## Canonical local web hub on :8898

For the browser control surface a person or agent should use the managed
launcher, not a hand-built Python command:

```sh
cd ~/hexapod/hexapod_walker/prototype_sts3215
make web-8898-start
make web-8898-status
make web-8898-restart
make web-8898-stop
```

This runs on the Mac via `uv run` and `launchctl`, resolves
`hexapod.local` to the current robot IP when possible, and serves both
`https://localhost:8443/rl` (the gamepad-ready URL) and the legacy
`http://localhost:8898/rl`. The first HTTPS visit uses a long-lived
self-signed certificate, so accept the browser warning once. Override the
robot target for one run with
`HEXAPOD_HOST=http://<robot-ip>:8080 make web-8898-restart`. Logs are in
`/tmp/hexapod_web_8898.log` and `make web-8898-logs` tails them.

To use a browser-trusted certificate instead, set both
`SIM_WEB_TLS_CERT_FILE` and `SIM_WEB_TLS_KEY_FILE` before restarting. The
HTTPS port can be changed with `SIM_WEB_HTTPS_PORT` (default `8443`).

`sim_web.sh` is the foreground/dev wrapper. It also uses `uv run`; by
default it starts a native `mujoco.viewer` window and serves the real
robot's `linux_control/webui/` at `https://127.0.0.1:8443/rl` (with HTTP
still available at `http://127.0.0.1:8898/rl`). The web
page is the controller; the MuJoCo window is the visual surface. The
shared UI routes the RL tab's stand/lower/held-key
drive/policy-picker commands into the local sim session. Sim-only
controls live under `/api/sim/*` and are shown only against this
backend: reset stand, reset belly, fall, recover, and push.

MuJoCo command cues are shared by the native viewer, browser frames,
interactive players, and policy-test videos: green points along the planar
joystick command, amber curves clockwise/counterclockwise for commanded yaw,
and blue points vertically during rise/lower commands. These are render-only
geometries and never participate in physics.

The browser JPEG preview is off in native-viewer mode. For headless
debugging, run `uv run python -m rl_move.sim.web_server` without `--viewer`,
or pass `--browser-frames on` if you intentionally want both surfaces.
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

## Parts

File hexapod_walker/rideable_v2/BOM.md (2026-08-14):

# `rideable_v2` — Bill of Materials & Shopping List

> Orderable BOM for **one rideable hexapod**, consistent with
> [`README.md`](README.md), [`DRIVETRAIN.md`](DRIVETRAIN.md),
> [`STRUCTURE.md`](STRUCTURE.md), [`POWER_SYSTEM.md`](POWER_SYSTEM.md).
> Actuator prices and Gates belt part numbers **live-verified Aug
> 2026**; everything else is order-of-magnitude. SKU-level engineering
> detail (part numbers, center distances, bushings, fallback SKUs) is
> in [`PARTS.md`](PARTS.md).
>
> **Status: design draft, unbuilt.** De-risk by buying **one AK80-64 +
> one belt stage + one pin lock + one bearing set** first and building
> the single-joint bench rig in [§L](#l-bench-test-order-de-risk-before-buying-18)
> before committing to 18.

---

## A. Actuators (the long pole — one SKU)

| Qty | Item | Spec to buy | Unit $ | Line $ | Link |
|---:|---|---|---:|---:|---|
| 18 | **CubeMars AK80-64 KV80** | 120 N·m peak / 48 N·m rated, 64:1, 48 rpm rated @ 48 V, 19 A peak / 7 A rated, 850 g, 12S max, CAN, XT30. **6 yaw + 6 hip-pitch + 6 knee** — one spare pool. Confirm the driver-board option is included at checkout. | $890 | **$16,020** | [store.cubemars.com AK80-64](https://store.cubemars.com/products/ak80-64) |
| — | *(alternative, decide at order time)* | **CubeMars AKH70-48 V1.0** — 222 N·m peak / 74 N·m rated, 1.4 kg, dual-CAN, $698.90. Hip fallback at 3:1 if the margin looks short on the bench rig — see [`DRIVETRAIN.md` §7](DRIVETRAIN.md#7-the-akh70-48-alternative). | ($699) | (−$3,438 if ×18) | [cubemars.com AKH70-48](https://www.cubemars.com/product/akh70-48-v-1-0-kv41-hollow-shaft-planetary-actuator.html) |
| | | | **Actuators subtotal** | **$16,020** | |

---

## B. Belt stages (18 sets)

Gates **Poly Chain GT Carbon 8MGT × 36 mm**. Small sprockets are Gates
stock (there is no stock 24T — the hip is 25T→100T); large driven
pulleys are lightened aluminum, machined with the joint-hub bolt circle
and the parking-pin hole ring. Belt lengths are stock catalog sizes;
full drive geometry in [`PARTS.md` §2](PARTS.md#2-belt-drives-18-stages).

| Qty | Item | Spec to buy | Unit $ | Line $ |
|---:|---|---|---:|---:|
| 6 | **Hip stage: 25T + 100T pulleys + belt + tensioner/guard** | 100T Ø254.6 mm PD lightened Al driven pulley (machined, with lock ring), 25T stock drive sprocket, **8MGT-960-36** belt, C≈208 mm, eccentric idler + guard. | $250 | $1,500 |
| 6 | **Knee stage: 28T + 84T + femur belt + tensioner/guard** | 84T Ø213.9 mm at the knee (with lock ring), 28T stock at the hip-end motor (~140 mm from the hip axis), **8MGT-896-36** belt, C≈212 mm down the femur, idler + full-length guard. | $250 | $1,500 |
| 6 | **Yaw stage: 36T + 72T + belt + tensioner** | 72T Ø183.3 mm large-bore driven pulley on the yaw bearing, 36T stock drive, **8MGT-720-36** belt, C≈136 mm. | $180 | $1,080 |
| | | | **Belt subtotal** | **$4,080** |

> **Chain fallback:** if the Gates rating disappoints at the hip, v1's
> duplex #40 chain (12T→48T for 4:1) drops into the same envelope —
> heavier and needing lube, but with known 27.8 kN ultimate strength.

---

## C. Structural joint-bearing assemblies (18)

The load-path decision ([`DRIVETRAIN.md` §4](DRIVETRAIN.md#4-the-structural-joint-bearing-the-load-path-decision)):
foot loads go **shaft → paired bearings → link**, never into the
actuator's output bearing.

| Qty | Item | Spec to buy | Unit $ | Line $ |
|---:|---|---|---:|---:|
| 12 | **Hip/knee joint set** | Hollow 25–30 mm shaft, 2 × tapered-roller bearings (moment-load pair), machined housing/clevis bores, pulley bolt circle. | $150 | $1,800 |
| 6 | **Yaw joint set** | Thin-section four-point-contact bearing (large bore for cable pass-through), seat machining. | $120 | $720 |
| | | | **Bearings subtotal** | **$2,520** |

---

## D. Parking pin locks (12)

Spring-applied / solenoid-retracted / power-off-engaged, **at the
joint** (pin into the driven pulley's hole ring) — 6 hip-pitch + 6
knee, **all 12 required**
([`DRIVETRAIN.md` §6](DRIVETRAIN.md#6-load-holding-joint-side-parking-pin-locks-v1s-rule-better-hardware)).
Mostly shop-built from catalog pieces; per-piece SKUs in
[`PARTS.md` §4](PARTS.md#4-parking-pin-locks-12), including why COTS
friction brakes (INTORQ BFK458 class, 4–8 kg each) lost.

| Qty | Item | Spec to buy | Unit $ | Line $ |
|---:|---|---|---:|---:|
| 12 | **Parking pin lock assembly** | Ø12 hardened dowel + double-shear clevis block + return spring + **24 V tubular pull solenoid (~25 W pull / 12 W hold, 12 mm stroke)** + hardened ring bushings in the pulley web. ~0.35 kg. | $80 | **$960** |

**Drivetrain grand subtotal (A+B+C+D): ~$23,580** — the figure headlined
in [`README.md` §7](README.md#7-cost-roll-up).

---

## E. Legs (6 × 6061-T6)

| Qty | Item | Spec | Line $ |
|---:|---|---|---:|
| ~15 m | 60×40×3 box + Ø50×3 tube, 6061-T6 | Femurs + tibias ([`STRUCTURE.md`](STRUCTURE.md)) | $400 |
| 1 lot | Machined hub blocks, clevises, hard-stop tabs | CNC, 6 legs | $1,200 |
| 1 lot | Doubler plates, tensioner pads, misc | | $400 |
| | | **Legs subtotal** | **$2,000** |

## F. Feet

| Qty | Item | Spec | Line $ |
|---:|---|---|---:|
| 6 | Urethane pad + Al disc + load-cell boss | 60A cast urethane; sensor itself in §H | $400 |

## G. Chassis, saddle & rider interface

| Qty | Item | Spec | Line $ |
|---:|---|---|---:|
| 1 | Welded 6061 tube frame + deck, ~880 mm wide | carries yaw mounts, battery, e-bay | $1,600 |
| 1 | Saddle + suspension seatpost | | $250 |
| 1 | 4-point harness | | $150 |
| 2 | Footpegs + mounts | | $120 |
| 1 | Handlebar + grips + e-stop mount | | $180 |
| | | **Chassis subtotal** | **$2,300** |

## H. Battery & power (12S bus)

| Qty | Item | Spec | Line $ |
|---:|---|---|---:|
| 1 | **12S Li-ion pack ~40 Ah / 1.8 kWh**, BMS ≥ 100 A | 50.4 V full — **12S, not 13S** ([`POWER_SYSTEM.md`](POWER_SYSTEM.md)) | $550 |
| 1 | 12S balance charger | | $130 |
| 1 | Main contactor ≥120 A + pre-charge | | $120 |
| 1 | Class-T fuse ~100 A + holder | | $50 |
| 1 | Fused branch bus bar + 6 × 30 A | one per leg | $60 |
| 1 | 48→24 V DC-DC **≥ 350 W** | 12 lock solenoids + logic | $80 |
| 1 lot | 6 AWG main / 12 AWG branch wire, XT30s, lugs | | $210 |
| | | **Battery + power subtotal** | **$1,200** |

## I. Control electronics & sensors

| Qty | Item | Spec | Line $ |
|---:|---|---|---:|
| 1 | Compute (Jetson Orin Nano class) | gait + IK + estimation over CAN | $500 |
| 2–3 | CAN interfaces | 18 nodes on 2–3 buses | $180 |
| 1 | 9-DOF IMU | body attitude | $300 |
| 6 | Foot load cell + amp | contact/force per foot | $270 |
| 12 | Lock-solenoid drivers (fail-safe, default-open, PWM economizer) | | $96 |
| 1 lot | Signal wiring, connectors, glands, carriers | | $354 |
| | | **Electronics subtotal** | **$1,700** |

## J. Fasteners, machining & misc hardware

| Qty | Item | Line $ |
|---:|---|---:|
| 1 lot | M8/M10 10.9 fasteners, nylocs, washers | $500 |
| 1 lot | Motor/lock mount + bracket machining | $700 |
| 1 lot | Misc bearings, keys, bushings, shims | $300 |
| | **Hardware subtotal** | **$1,500** |

## K. Consumables & finishing

| 1 lot | Threadlocker, heat-shrink, paint, pinch-point decals, guards | **$400** |
|---|---|---:|

---

## Grand total

| Bucket | Cost (USD, Aug 2026) |
|---|---:|
| A. Actuators (18 × AK80-64) | $16,020 |
| B. Belt stages (18) | $4,080 |
| C. Joint-bearing assemblies (18) | $2,520 |
| D. Parking pin locks (12) | $960 |
| **→ Drivetrain subtotal** | **$23,580** |
| E. Legs | $2,000 |
| F. Feet | $400 |
| G. Chassis + rider interface | $2,300 |
| H. Battery + power | $1,200 |
| I. Electronics + sensors | $1,700 |
| J. Hardware + machining | $1,500 |
| K. Consumables | $400 |
| **Full-build estimate** | **~$33,080 (≈ $31–36 k)** |
| Recommended spares (1 actuator + 1 lock + 1 belt set) | +$1,220 |

Roughly **$8 k under v1** with less than half the mass — the AK80-64's
torque density, the belt stages, and $960 of pin locks doing the work
the RMD-X15s' price tags and $3k of brakes did in v1.

---

## L. Bench-test order (de-risk before buying 18)

1. Buy **1 × AK80-64 + 1 hip belt stage + 1 pin-lock kit + 1 hip
   bearing set** (~$1,370).
2. Build a single hip-joint rig: actuator → 4:1 belt →
   bearing-supported shaft → lever arm loaded to **0.36 kN·m**.
3. Verify the **pin lock holds** the loaded joint at zero motor current
   (no creep, no ring deformation), **engages on power-off**, and that
   a deliberate mid-motion power cut settles ≤15° onto the pin without
   drama (add the phase-short relay if the settle is harsh).
4. Verify **418 N·m peak** against a stop without belt tooth-jump or
   thermal fault, and measure real stage efficiency vs the assumed 0.87.
5. **Get Gates application engineering to sign off** the three drives
   (hip 8MGT-960-36 at 3.28 kN transient / 1.31 kN continuous is the
   worst) — catalog-anchored margin is >2×, but certify it.
6. Measure hip thermal at a simulated walk duty cycle; decide 4:1 vs
   5:1 vs AKH70-48 hips **now**, while it's a pulley/PO change.
7. Only then order the remaining 17 actuators, 17 stages, 11 locks,
   17 bearing sets.

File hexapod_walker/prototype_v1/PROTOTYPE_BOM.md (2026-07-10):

# Hexapod Prototype BOM

This is the controlled bill of materials for **one complete tabletop
hexapod prototype**. The design is built around **DS3225 servos**; do not
substitute other servo models unless you are ready to measure them and
regenerate the printed wells.

Links are stable Amazon search links rather than one-off ASINs, because
Amazon listings churn. Pick a well-reviewed Prime listing that matches the
spec exactly.

## Required Purchases

| Qty | Item | Spec to buy | Link |
|---:|---|---|---|
| 20 | DS3225 servo | **DS3225 25 kg-cm metal gear digital servo**, standard-size case, ~40 x 20 x 38 mm body, ~54 mm tab span. Buy all 20 from the same listing/batch. 18 used + 2 spares. | [Amazon: DS3225 servo 25kg metal gear](https://www.amazon.com/s?k=DS3225+servo+25kg+metal+gear) |
| 1 | Raspberry Pi | Raspberry Pi 4 or Pi 5, 4 GB+ RAM. Runs Python gait/RL/teleop and talks USB serial to Arduino. | [Amazon: Raspberry Pi 5 4GB kit](https://www.amazon.com/s?k=Raspberry+Pi+5+4GB+kit) |
| 1 | Pi power supply | Official or equivalent USB-C 5 V supply, 3 A minimum for Pi 4, 5 A preferred for Pi 5. | [Amazon: Raspberry Pi USB C power supply](https://www.amazon.com/s?k=Raspberry+Pi+USB+C+power+supply) |
| 1 | microSD card | 32 GB or 64 GB, A1/A2 rated. | [Amazon: 32GB A1 microSD card](https://www.amazon.com/s?k=32GB+A1+microSD+card) |
| 1 | Arduino Mega 2560 | Mega 2560 R3 compatible board. Acts as the real-time USB-to-PCA9685 servo bridge. | [Amazon: Arduino Mega 2560 R3](https://www.amazon.com/s?k=Arduino+Mega+2560+R3) |
| 2 | PCA9685 servo driver | 16-channel I2C PWM servo driver boards. One at `0x40`, one at `0x41`. | [Amazon: PCA9685 16 channel servo driver](https://www.amazon.com/s?k=PCA9685+16+channel+servo+driver) |
| 1 | LiPo battery | 3S 2200 mAh, 25C or higher, XT60 connector. | [Amazon: 3S 2200mAh 25C lipo XT60](https://www.amazon.com/s?k=3S+2200mAh+25C+lipo+XT60) |
| 2-3 | 6.0 V high-current regulator ("the buck") | **Castle Creations CC BEC PRO (P/N 010-0004-01)**, 20 A peak / ~15 A continuous, output **locked to 6.0 V** via Castle Link. **Split the 18 servos across 2-3 of these on separate fused rails** — do NOT feed ~9 servos from one 5 A BEC (that melted the V+ wires). ⚠ The old "2 × 5-6 V BEC 5 A" entry and any generic "20 A / 300 W adjustable buck" are RETIRED for the servo rail: 5 A is badly undersized for the ~40 A stand-up peak, and the adjustable buck overvolted the servos to ~10 V and failed short. See `POWER_SYSTEM.md`. | [Castle CC BEC PRO 010-0004-01](https://www.castlecreations.com/en/bec-voltage-regulator/cc-bec-pro-010-0004-01) |
| 1 | Main fuse — MIDI/ANL, 30 A | Bolt-down 30 A MIDI/ANL fuse + inline holder, mounted within ~15 cm of the LiPo + terminal on the 12 AWG main lead. Protects the whole downstream system; sized to the main-lead ampacity, not the load. | [Amazon: MIDI ANL inline fuse holder 30A](https://www.amazon.com/s?k=MIDI+ANL+inline+fuse+holder+30A) |
| 1 | Per-rail fused distribution block | **Blue Sea Systems ST-Blade fuse block** (100 A block / 30 A per circuit) — one **ATC blade fuse per servo rail**, sized to that rail's wire (10 A on 16 AWG / 3-servo rails, 15 A on 14 AWG / 6-servo rails). The fuse must blow before the wire melts. | [Amazon: Blue Sea ST blade fuse block](https://www.amazon.com/s?k=Blue+Sea+ST+blade+fuse+block) |
| 1 | Assorted ATC blade fuses | 10 A + 15 A ATC/ATO blade fuses (+ spares) for the per-rail distribution block above. | [Amazon: ATC ATO blade fuse assortment 10A 15A](https://www.amazon.com/s?k=ATC+ATO+blade+fuse+assortment) |
| 1 | 6 V power distribution bus bar | Positive + negative bus bar / junction block (100 A dual-stud, M6/M8) to distribute regulated 6 V to the per-rail feeds and inject V+ into BOTH PCA9685 boards. Never run all rail current through one PCA screw terminal (that burned a board's V+ trace). | [Amazon: 12v 100A bus bar M6 stud](https://www.amazon.com/s?k=12v+100A+bus+bar+M6+stud) |
| 1 | 12 AWG silicone wire (main) | Fine-strand silicone, red + black, for the LiPo main lead and regulator feeds (~15-22 A). | [Amazon: 12 AWG silicone wire red black](https://www.amazon.com/s?k=12+AWG+silicone+wire+red+black) |
| 1 | 14/16 AWG silicone wire (rails) | Fine-strand silicone for per-rail 6 V feeds, gauge sized to each rail's fuse (14 AWG for 15 A rails, 16 AWG for 10 A rails). | [Amazon: 14 AWG 16 AWG silicone wire](https://www.amazon.com/s?k=14+16+AWG+silicone+wire) |
| 1 | Hardware power cutoff (e-stop) | **30/40 A automotive SPST relay + Arduino relay-driver module** (transistor + flyback diode) on the 12 V feed to the regulators. **Defaults OFF** at power-on/reset; an Arduino GPIO must actively arm it, and DISARM/E-STOP/watchdog opens it. The software "disarm" only stops PWM (firmware `X` = limp) — this removes POWER for a real e-stop. Keep the manual anti-spark switch as the physical e-stop too. | [Amazon: arduino relay module 30A automotive](https://www.amazon.com/s?k=arduino+relay+module+30A+automotive) |
| 1 | Current sensor (overcurrent auto-cutoff) | **ACS758-050B** hall sensor (isolated, on the main lead, reads on one Arduino ADC) so firmware can AUTO-DISARM + open the cutoff on overcurrent. Optional add: **INA226** I²C shunt monitor for per-rail digital amps — ⚠ jumper its address OFF 0x40 (PCA9685 clash) to 0x44/0x45, or put it on the Pi's I²C bus. See `POWER_SYSTEM.md` §9. | [Amazon: ACS758 current sensor 50A](https://www.amazon.com/s?k=ACS758+current+sensor+50A) |
| 1 | LiPo charger | 3S balance charger, e.g. SkyRC B6 style or better. | [Amazon: 3S lipo balance charger](https://www.amazon.com/s?k=3S+lipo+balance+charger) |
| 1 | LiPo safety bag | Fire-resistant charging/storage bag. | [Amazon: lipo safety bag fireproof](https://www.amazon.com/s?k=lipo+safety+bag+fireproof) |
| 1 | Anti-spark switch | XT60 RC LiPo anti-spark/on-off switch for servo rail power. | [Amazon: rc lipo anti-spark switch xt60](https://www.amazon.com/s?k=rc+lipo+anti-spark+switch+xt60) |
| 2 | XT60 pigtails | Male/female XT60 silicone-wire pigtails, 12-14 AWG. | [Amazon: XT60 pigtail 12awg](https://www.amazon.com/s?k=XT60+pigtail+12awg) |
| 1 | Servo extensions | 20-pack, 3-pin male-female, 30 cm.  The 18-servo harness uses 12 stock DS3225 pigtails on their own + 6 stock pigtails-plus-one-30cm-extension; see `pi_control/wire_harness_plan.py` for the per-joint table (auto-generated, validated by `_verify_prototype.check_harness_reach`). | [Amazon: servo extension cable 30cm 20 pack](https://www.amazon.com/s?k=servo+extension+cable+30cm+20+pack) |
| 1 | Nylon zip-ties, 100-pack | 24 used for cable strain relief: 3 per leg at the cradle `cable_zip_post`s (yaw / hip / knee) + 1 per leg looped through the chassis_bottom leg-harness drop slot (each leg's cable drop slot doubles as the zip-tie anchor -- pass a zip-tie through the slot to bundle the per-leg harness).  2-3 mm wide, ~ 100 mm long. | [Amazon: nylon zip ties 4 inch 100 pack](https://www.amazon.com/s?k=nylon+zip+ties+4+inch+100+pack) |
| 1 | Dupont jumper kit | Mixed M-F / F-F / M-M jumper wires for I2C and logic wiring. | [Amazon: dupont jumper wires 120 pcs](https://www.amazon.com/s?k=dupont+jumper+wires+120+pcs) |
| 1 | USB cable, Pi to Arduino | USB-A to USB-B if using Arduino Mega with full-size USB-B. If your clone uses USB-C or micro-USB, buy that cable instead. | [Amazon: USB A to B cable Arduino](https://www.amazon.com/s?k=USB+A+to+B+cable+Arduino) |
| 1 | M3 screw assortment | M3 socket-head screws, nuts, washers, lengths 6/8/10/12/16/20 mm. | [Amazon: M3 stainless screw kit assortment](https://www.amazon.com/s?k=M3+stainless+screw+kit+assortment) |
| 6 | M3 x 16 pan-head bolts | Foot/tibia hinge pin -- one per leg.  Passes through the foot_pad's FORK (3.5 + 6.4 + 3.5 = 13.4 mm) and engages an M3 nylock on the far cheek; the tibia's TANG sits in the slot (May 2026 inversion: fork on the foot, tang on the tibia -- pre-2026 it was the other way round, same pin + nut + 16 mm length).  Pan-head (low profile), threaded full length.  Stainless.  Reuse from the M3 assortment if it includes 16 mm. | [Amazon: M3 x 16 pan head stainless](https://www.amazon.com/s?k=M3+x+16+pan+head+stainless) |
| 1 | M3 nyloc nuts | 100-pack nylon-insert lock nuts. **10 used as of the May 2026 tray-mount fix:** 6 on the foot-pad hinge pins (one per leg) + 4 UNDER chassis_bottom retaining the brass M-F standoffs' male threads on the rotated-45-deg 35-mm-radius pattern (CHASSIS_STANDOFF_HOLES_XY).  The 72 cradle servo mounts still thread into brass heat-set inserts (see below) and do NOT use a nut.  Earlier docs (pre-2026 coxa-bracket flange) counted 24 + 6; that flange has been retired. | [Amazon: M3 nyloc lock nut 100 pack](https://www.amazon.com/s?k=M3+nyloc+lock+nut+100+pack) |
| 1 | M3 heat-set inserts (`94459A130`) | McMaster knurled brass M3 heat-set insert, Phi 4.0 mm pilot, Phi 5.7 mm OD, 5.0 mm length. **62 used** under the May 2026 Design E mixed-mode cradle scheme + tray-mount fix: 36 in the cradles (the 2 -X bolts per cradle only -- the 2 +X bolts self-tap into Phi 2.5 mm pilots) + 4 in the battery_holder feet + 8 in the electronics_tray (4 Mega + 4 primary PCA9685) + 4 more in the electronics_tray (secondary PCA9685) + 4 in the imu_pad (MPU-6050 mount) + 2 in chassis_top's printed bosses (switch_holster) + **4 in chassis_bottom's new tray-mount bosses on the (±24.75, ±24.75) pattern (May 2026 tray-mount fix)**. Installed with a soldering iron at ~220 deg C, light downward pressure, ~10-15 s per insert, then cool ~30 s; an M3 x 8 SHCS (-X cradle bolts / board mount / IMU pad) or M3 x 10 SHCS (battery_holder foot / switch_holster) threads into the brass instead of self-tapping into plastic.  Same SKU re-used everywhere M3 inserts appear in the printed-parts BOM.  (Down from the 94 of the brief all-heat-set Design D iteration; commit history under "Design E" for the +X channel-vs-boss conflict that forced the partial revert.) | [McMaster 94459A130](https://www.mcmaster.com/94459A130/) |
| 1 | M2.5 heat-set inserts (`94459A106`) | McMaster knurled brass M2.5 heat-set insert, Phi 3.0 mm pilot, Phi 3.6 mm OD, 4.0 mm length.  **4 used** -- electronics_tray Raspberry Pi 4 / Pi 5 board-mount bosses (May 2026 hardware-arrival pass).  Same soldering-iron install workflow as the M3 inserts; the printed Phi 6 mm boss around each pilot leaves a 1.5 mm plastic wall, which is enough for thermal install without slumping. | [McMaster 94459A106](https://www.mcmaster.com/94459A106/) |
| 1 | M3 x 10 SHCS (`91290A114`) | M3 x 10 mm socket-head cap screw, black-oxide steel.  **10 used:** 4 battery-holder foot bolts (UP from under chassis_bottom into the holder feet's M3 inserts) + 2 switch_holster mount bolts (DOWN through the holster ear into chassis_top boss inserts) + **4 chassis_top → brass-standoff bolts (DOWN from above chassis_top into the M-F standoff female top threads on the rotated-45-deg 35-mm-radius pattern; May 2026 tray-mount fix)**. | [McMaster 91290A114](https://www.mcmaster.com/91290A114/) |
| 1 | M3 x 8 SHCS (`91290A113`) | M3 x 8 mm socket-head cap screw, black-oxide steel.  **92 used:** 72 cradle servo mounts + 4 Mega 2560 + 4 primary PCA9685 + 4 secondary PCA9685 + 4 imu_pad (MPU-6050 mount) + **4 electronics_tray → chassis_bottom tray-mount bolts (DOWN through the tray's flush-recessed cbores into M3 heat-set inserts in chassis_bottom's tray-mount bosses on the (±24.75, ±24.75) pattern; May 2026 tray-mount fix)**.  Buy a 100-pack so you have spares. | [McMaster 91290A113](https://www.mcmaster.com/91290A113/) |
| 1 | M2.5 x 8 SHCS (`91290A102`) | M2.5 x 8 mm socket-head cap screw, black-oxide steel.  4 used at the electronics_tray Raspberry Pi 4 / Pi 5 board-mount sites (May 2026 hardware-arrival pass); same stock as the DS3225 servo spline screw `91290A104` so a single 50-pack covers both roles. | [McMaster 91290A102](https://www.mcmaster.com/91290A102/) |
| 1 | M3 standoffs | M3 x 32 mm male-female brass standoffs, pack of 20.  **4 used** on the rotated-45-deg 35-mm-radius pattern (`CHASSIS_STANDOFF_HOLES_XY` = (±35, 0) and (0, ±35); May 2026 tray-mount fix moved them OFF the (±24.75, ±24.75) tray-mount pattern so they no longer conflict with the heat-set inserts in chassis_bottom's tray-mount bosses).  Earlier May 2026 audit also bumped 25 mm -> 32 mm so the 28 mm-tall battery_holder fits between the chassis plates with 4 mm headroom (CHASSIS_GAP = 32 mm in hexapod_prototype.py).  Male thread drops DOWN through chassis_bottom's Phi 3.4 mm clearance hole at the standoff pattern and is captured by an M3 nyloc nut underneath; female top accepts the M3 × 10 SHCS dropped DOWN from above chassis_top.  Re-verify lengths whenever CHASSIS_GAP changes. | [Amazon: M3 32mm standoffs male female brass](https://www.amazon.com/s?k=M3+32mm+standoffs+male+female+brass) |
| 1 | M2.5 screw pack | M2.5 x 8 mm screws, useful for horn/adapter work if the servo-included screws are bad; also the same stock that the Raspberry Pi mount uses (above). | [Amazon: M2.5 8mm screw 50 pack](https://www.amazon.com/s?k=M2.5+8mm+screw+50+pack) |

<!-- BEGIN FASTENERS (auto-generated by scripts/render_fastener_bom.py) -->

## Fasteners

Auto-derived from `fastener_registry.build_all_fastener_instances()`.
Edit the registry (not this table) and re-run `make bom-fasteners`.

| Spec | McMaster P/N | Qty | Used in |
|---|---|-----|---|
| M3x6 SHCS | 91290A111 | 72 | link-to-disc-horn bolts |
| M2.5x8 spline screw | 91290A104 | 18 | servo spline center screws |
| M2.5x8 SHCS into heat-set insert | 91290A102 | 4 | electronics_tray heat-set inserts (Mega + Pi + 2 x PCA9685) |
| M2.5 heat-set insert | 94459A106 | 4 | electronics_tray heat-set inserts (Mega + Pi + 2 x PCA9685) |
| M3x8 SHCS into heat-set insert | 91290A113 | 56 | cradle servo mounts (M3 SHCS into heat-set insert), electronics_tray chassis-mount bolts (M3 x 8 SHCS into chassis_bottom heat-set insert), electronics_tray heat-set inserts (Mega + Pi + 2 x PCA9685), imu_pad heat-set inserts (MPU-6050 mount) |
| M3x8 SHCS self-tap | 91290A113 | 36 | cradle servo mounts (M3 SHCS self-tap) |
| M3x10 SHCS | 91290A114 | 10 | battery_holder heat-set inserts, chassis_top brass standoff bolts (M3 x 10 SHCS into standoff female thread), switch_holster heat-set inserts |
| M3 heat-set insert | 94459A130 | 62 | battery_holder heat-set inserts, chassis_bottom tray-mount heat-set inserts, cradle heat-set inserts, electronics_tray heat-set inserts (Mega + Pi + 2 x PCA9685), imu_pad heat-set inserts (MPU-6050 mount), switch_holster heat-set inserts |
| M3x16 pan-head | 92010A130 | 6 | foot hinge pins |
| M3 nyloc nut | 90576A102 | 10 | chassis_bottom brass standoff retention nuts, foot hinge pins |
|  |  | **278** | **total fasteners** |

Notes:
- Cradle servo mounts (72 x `M3x8 SHCS into heat-set insert` /
  `91290A113`) are driven VERTICALLY from above each servo ear and
  thread into an M3 brass heat-set insert (`94459A130`) installed
  flush with the boss top.  May 2026 fix: the previous self-tap
  pilots grazed the cradle wall material at 7 of 12 sites (audit:
  0.00-1.50 mm of plastic radially); the heat-set switch forces
  Phi 8 mm bosses around every pilot and gives real metal threads.
- Heat-set inserts (72 x `94459A130`) are installed BEFORE the
  servo cradle is mated to its neighbour: heat the insert with a
  soldering iron at ~220 deg C, drop it into the printed Phi 4 mm
  x 6 mm pocket, apply light downward pressure for ~10-15 s until
  the knurl displaces plastic into the boss wall, then cool ~30 s
  before threading the M3 x 8 SHCS in.
- Link-to-disc-horn bolts (72 x M3x6 SHCS / `91290A111`) thread
  DIRECTLY into the 20 mm aluminium 25T disc horn's 4 x M3 TAPPED
  holes on a 14 mm bolt circle (June 2026 disc-horn switch, replacing
  the old plastic 4-arm X-horn + M2 self-tap scheme).  The aluminium
  IS the thread-engagement medium -- no heat-set, no self-tap into
  plastic.  M3 x 6 screws usually ship with the disc-horn 10-packs
  (Amazon B07D56FVK5); `91290A111` is the McMaster equivalent for
  spares.  See `fasteners/README.md` for the full rationale.
- Captive nyloc nuts are used at the foot-pad hinge pins (6 total,
  one per leg); the through-hole bolt is captured by the nyloc on
  the opposite side of the foot.  The previous 24 x M3 x 14
  coxa-bracket-to-chassis nyloc'd through-bolts were retired in
  the May 2026 chassis_bottom-integrated yaw cradle redesign --
  the printed bracket flange they clamped is gone, replaced by
  per-leg cradle bosses inside chassis_bottom.
- The M2.5 spline center screw ships with each DS3225-class servo --
  it's listed here so the screwdriver-access verifier check knows the
  fastener exists, but you do NOT order it separately.
- See `fasteners/README.md` for the McMaster STEP swap-in flow if you
  want to replace the parametric fallback geometry with real CAD.

<!-- END FASTENERS -->
| 1 kg | PLA or PETG filament | 1.75 mm. Structural printed parts. PLA is easiest; PETG is tougher. | [Amazon: PLA filament 1.75mm 1kg](https://www.amazon.com/s?k=PLA+filament+1.75mm+1kg) |
| 250 g | TPU 95A filament | Foot pads. If you skip TPU, print feet in PLA and glue rubber tread into the cups. | [Amazon: TPU 95A filament 1.75mm](https://www.amazon.com/s?k=TPU+95A+filament+1.75mm) |
| 1 | Heat-shrink kit | Assorted small heat-shrink tubing for power wiring cleanup. | [Amazon: heat shrink tubing assorted](https://www.amazon.com/s?k=heat+shrink+tubing+assorted) |

## Strongly Recommended Tools

| Qty | Item | Why | Link |
|---:|---|---|---|
| 1 | Digital calipers | Check DS3225 body/tab dimensions before printing all six legs. | [Amazon: digital calipers](https://www.amazon.com/s?k=digital+calipers) |
| 1 | Soldering iron kit | PCA9685 boards often need header pins soldered. | [Amazon: soldering iron kit beginner](https://www.amazon.com/s?k=soldering+iron+kit+beginner) |
| 1 | Metric hex key set | M3 socket-head screws usually need a 2.5 mm hex key. | [Amazon: metric ball end hex key set](https://www.amazon.com/s?k=metric+ball+end+hex+key+set) |
| 1 | Super glue gel | Foot tread / small print fixes. | [Amazon: super glue gel](https://www.amazon.com/s?k=super+glue+gel) |
| 1 | Needle file set | Useful if a servo well or femur slot is slightly tight from FDM over-extrusion. | [Amazon: needle file set](https://www.amazon.com/s?k=needle+file+set) |

## Printed Parts

Files are in `hexapod_walker/prototype/stl_prototype/`.

| Qty | STL |
|---:|---|
| 1 | `chassis_top.stl` |
| 1 | `chassis_bottom.stl` |
| 1 | `battery_holder.stl` |
| 1 | `electronics_tray.stl` |
| 1 | `bec_cradle.stl` |
| 1 | `switch_holster.stl` |
| 6 | `coxa_bracket.stl` |
| 6 | `coxa_link.stl` |
| 6 | `femur_link.stl` |
| 6 | `tibia_link.stl` |
| 6 | `foot_pad.stl` |

Design B (May 2026) retired the printed `servo_horn_adapter` -- each
link now bolts DIRECTLY onto a purchased servo horn, so it no longer
appears in the printed-parts set.  June 2026 disc-horn switch: the
purchased horn is now a 20 mm aluminum 25T disc (Amazon B07D56FVK5),
bolted with 4 x M3 x 6 SHCS on a 14 mm bolt circle into the disc's
M3 tapped holes (replacing the old plastic 4-arm X-horn + M2 scheme).

For a one-leg test, print only:

| Qty | STL |
|---:|---|
| 1 | `coxa_bracket.stl` |
| 1 | `coxa_link.stl` |
| 1 | `femur_link.stl` |
| 1 | `tibia_link.stl` |
| 1 | `foot_pad.stl` |

## Bench Test Order

1. Buy **one DS3225** first if you want to de-risk fit.
2. Print `coxa_bracket.stl`, `coxa_link.stl`, `femur_link.stl` (the servo horn is the purchased 20 mm aluminum disc, not a printed part).
3. Confirm the DS3225 slides into all three wells and the tab holes line up.
4. Wire one DS3225 to PCA9685 channel 0 and run:

```bash
python hexapod_walker/prototype/pi_control/servo_bridge_client.py --port /dev/ttyACM0 wiggle --joint 0
```

5. Once fit and motion are good, buy/print the rest.

## Rough Cost

| Bucket | Estimate |
|---|---:|
| DS3225 servos, 20 total | $260-$360 |
| Pi + power + microSD | $90-$130 |
| Arduino + PCA9685 + cables | $35-$60 |
| Battery + 6 V regulators (2-3× Castle CC BEC Pro) + charger + safety bag + switch | $200-$300 |
| Power path: main fuse + fused distro + bus bar + silicone wire + e-stop relay + current sensor | $70-$110 |
| Fasteners / standoffs / wiring consumables | $40-$70 |
| Filament | $25-$40 |
| **Total** | **~$720-$1080** |

If you already own a Raspberry Pi, charger, tools, or filament, the actual
cash outlay is much lower.

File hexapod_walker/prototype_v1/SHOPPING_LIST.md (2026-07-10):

# Hexapod prototype — shopping list & print queue

**Status: design verification PASSED** (manifoldness, cradle openness,
bolt-hole engagement, self-collision — all four checks clean against
`_verify_prototype.py`).

This is the everything-you-need-to-buy-and-print sheet. Numbers are
sized for **one complete walking robot** with a small spare margin
(~ 10% on fasteners, +2 servos).

> ⚠ **Power path was corrected after a string of power failures** (melted
> V+ wires, an overvolted buck that failed short, and smoke on stand-up).
> The battery/power rows in §B.2 now reflect the fixed spec — 6.0 V
> high-current regulators, per-rail + main fusing, a bus bar, an e-stop
> cutoff, and a current sensor. The full rationale, current budget, and
> bring-up checklist live in `POWER_SYSTEM.md`.

---

## A. STL files to print

All files live under `hexapod_walker/prototype/stl_prototype/`. Filenames are
exactly as the generator writes them.

| # | Filename | Qty | Material | Layer | Infill | Walls | Print time (Ender 3) | Notes |
|---|---|---:|---|---|---:|---:|---:|---|
| 1 | `chassis_top.stl` | **1** | PLA / PETG | 0.2 mm | 25% gyroid | 4 | ~ 2 h | Identical to bottom |
| 2 | `chassis_bottom.stl` | **1** | PLA / PETG | 0.2 mm | 25% gyroid | 4 | ~ 2 h | Identical to top |
| 3 | `battery_holder.stl` | **1** | PLA / PETG | 0.2 mm | 20% gyroid | 3 | ~ 1.5 h | LiPo tray |
| 4 | `electronics_tray.stl` | **1** | PLA / PETG | 0.2 mm | 20% gyroid | 2 | ~ 2 h | 160 x 130 mm deck for Arduino Mega 2560 + Raspberry Pi 4/5 + 2 x PCA9685 (May 2026 expansion + "essentials" 2nd-PCA bump) |
| 4a | `bec_cradle.stl` | **1** | PLA / PETG | 0.2 mm | 25% gyroid | 3 | ~ 0.3 h | Snap-fit clip for the 6 V regulators.  ⚠ The printed clip was sized for 2 × small 5 A BECs; the corrected power spec (`POWER_SYSTEM.md`) uses 2–3 × Castle CC BEC Pro (~43 × 33 × 24 mm each) which need airflow (§7 cooling), so re-check the cradle fit / spacing before printing — it may need regenerating for the larger regulators.  Sits on the electronics_tray. No fasteners (friction fit). |
| 4b | `switch_holster.stl` | **1** | PLA / PETG | 0.2 mm | 25% gyroid | 3 | ~ 0.3 h | Snap-in holster for anti-spark on/off switch.  Bolts to chassis_top's +X edge via 2 x M3 x 10 SHCS into 2 chassis_top heat-set inserts. |
| 4c | `imu_pad.stl` | **1** | PLA / PETG | 0.2 mm | 25% gyroid | 3 | ~ 0.2 h | 25 x 20 mm IMU mounting pad with 4 M3 heat-set insert bosses on the GY-521 15 x 11 mm hole pattern.  No fasteners between pad and chassis_top -- the pad is foam-taped to the chassis_top centre for vibration isolation. |
| 5 | `coxa_bracket.stl` | **6** | PLA / PETG | 0.2 mm | 30% gyroid | 4 | ~ 4 h total | Flange-down on bed; the well opens UP. The flange bolts to the chassis. |
| 6 | `coxa_link.stl` | **6** | PLA / PETG | 0.2 mm | 30% gyroid | 4 | ~ 4 h total | Hub face down on bed; the well opens UP. |
| 7 | `femur_link.stl` | **6** | PLA / PETG | 0.2 mm | 30% gyroid | 4 | ~ 5 h total | Spar's broad face flat on the bed (hip-pad flat).  Knee cradle opens through the print -- the cradle floor was REMOVED in the May 2026 supports-free refactor (cf. PROTOTYPE.md §3.2), so the part is now a 4-wall pen open at both Y faces and there is no ~30 × 40 mm bridged ceiling.  **NO SUPPORTS NEEDED** -- every overhang is < 45° in this orientation. |
| 8 | `tibia_link.stl` | **6** | PLA / PETG | 0.2 mm | 25% gyroid | 4 | ~ 4 h total | Spar's broad face flat on the bed.  May 2026 hinge inversion: the tibia is now `LINK_THICKNESS` = 6 mm wide in Y EVERYWHERE -- the foot end terminates in a single 6 mm tang (in-plane with the spar) instead of the old 12 mm-wide clevis (which used to stick 6 mm above the spar's broad face and required supports under the cheeks).  **NO SUPPORTS NEEDED** -- the part prints as a flat 6 mm-tall slab. |
| 9 | `foot_pad.stl` | **6** | TPU 95A (PLA OK) | 0.25 mm | 100% (TPU) | 3 | ~ 1 h | TPU = grip; PLA = slips.  May 2026 hinge inversion: foot now carries the 2-cheek FORK (3.5 mm cheeks + 6.4 mm slot) instead of a single tongue.  Print disk-on-bed, fork pointing UP -- the cheeks are 3.5 mm vertical TPU walls with no overhangs; the 6.4 mm slot between them is open air (no bridge).  **NO SUPPORTS NEEDED**. |

> **`servo_horn_adapter.stl` has been retired** (Design B, May 2026 -- commit
> `be06741`).  Each link now bolts DIRECTLY onto a purchased servo
> horn, so there is no printed adapter in the stack any more.  Skip
> this row if you have an older copy of this checklist.
>
> **June 2026 disc-horn switch:** the robot now drives a **20 mm
> aluminum 25T disc horn** (Amazon B07D56FVK5, "10Pcs Servo Horn Metal
> Aluminum 25T Silvery Servo Disc ... MG945 MG995 MG996") at every
> servo joint instead of the plastic 4-arm X-horn.  Each link bolts to
> the disc's flat top face with 4 x M3 x 6 SHCS on a 14 mm bolt circle,
> threading into the disc's M3 tapped holes.  You need 18 discs (3
> joints x 6 legs); the part ships in 10-packs, so order **2 packs**
> (2 spares + the M3 x 6 screws that come with them).

**Total print time (single Ender 3 / Bambu A1):** ~ 22 hours of
machine time, spread across 6 – 7 print sessions.

> **Don't have a printer?** The same files (re-oriented for MJF) live
> in `hexapod_walker/prototype/xometry_upload/` with a `manifest.csv` and a
> README that takes you through the Xometry / Shapeways / JLCPCB
> upload flow. Total there is ~ $580 in MJF PA12, vs ~ $20 in
> filament if you self-print.

If you only have a 220 × 220 mm printer (Ender 3), every part fits
the bed individually. The chassis plates (200 × 230 mm in their
default orientation) need to be rotated 30° to fit, or printed in
two halves and bolted — but most likely they fit on a 235 × 235 mm
hot bed (the actual usable area on most Ender 3 / Bambu A1 mini
printers) without rotation.

---

## B. Amazon shopping list (US, mid-2026)

> **Tip on the search links:** Amazon's URL format keeps the query
> intact, so the links below survive the inevitable ASIN churn.
> Pick the listing with the most reviews and `Prime` shipping. If
> you want the absolute cheapest, AliExpress / Banggood is roughly
> 50% cheaper but ships in 2 – 4 weeks.

### B.1 Servos (the controlled actuator for this design)

| Qty | Part | Why this one | Search link |
|---:|---|---|---|
| **20** | **DS3225 25 kg·cm digital servo, metal gear, standard-size case** | This is the actuator the printed wells were designed around: ~40 × 20 × 38 mm body, ~54 mm tab span, ~49.5 mm tab-hole spacing, output shaft offset ~10 mm from body centre. Buy one brand/listing and stick with it for all 20. Pack of 4 is usually $52 – $60; five 4-packs = 20 servos with 2 spares. | [Amazon search: "DS3225 servo 25kg metal gear"](https://www.amazon.com/s?k=DS3225+servo+25kg+metal+gear) |

**Buy the DS3225, not a random alternate 25 kg servo.** The model can be
regenerated for another servo, but the current STLs assume the DS3225
geometry above. Buy **20** total (18 needed + 2 spares — the weakest
link is gear stripping during tuning).

### B.2 Battery / power

| Qty | Part | Why | Search link |
|---:|---|---|---|
| 1 | **3S 2200 mAh LiPo, 25C+, XT60 connector** | 11.1 V nominal, ~ 30 min run time. "Zeee", "OVONIC", "CNHL", or "Tattu" are all fine. | [Amazon search: "3S 2200mAh 25C lipo XT60"](https://www.amazon.com/s?k=3S+2200mAh+25C+lipo+XT60) |
| 2–3 | **Castle Creations CC BEC PRO (010-0004-01), locked to 6.0 V** | The corrected servo-rail regulator. 20 A peak / ~15 A continuous each, output adjustable **and lockable** 4.9–12.5 V via Castle Link. **Split the 18 servos across 2–3 of these on separate fused rails.** ⚠ **RETIRES the old "2 × 5 A BEC" and any generic 20 A/300 W adjustable buck for the servo rail:** 5 A is badly undersized (9 servos ≈ 22 A stall → melted V+ wires), and the adjustable buck was run at ~10 V (overvolting the 4.8–6.8 V servos) and failed short. See `POWER_SYSTEM.md`. Budget alt: 5–6 × Hobbywing UBEC 10A HV, one per ~3–4 servos. | [Castle CC BEC PRO 010-0004-01](https://www.castlecreations.com/en/bec-voltage-regulator/cc-bec-pro-010-0004-01) |
| 1 | **Main fuse — 30 A MIDI/ANL + inline bolt-down holder** | Mount within ~15 cm of the LiPo + terminal on the 12 AWG main lead. The fuse protects the **wire** (must be ≤ wire ampacity), not the load — sized to the ~15–22 A the 12 V side carries at peak. | [Amazon search: "MIDI ANL inline fuse holder 30A"](https://www.amazon.com/s?k=MIDI+ANL+inline+fuse+holder+30A) |
| 1 | **Blue Sea ST-Blade fused distribution block + 10 A/15 A ATC blades** | One ATC blade fuse **per servo rail**, sized to that rail's wire (10 A on 16 AWG / 3-servo rails, 15 A on 14 AWG / 6-servo rails). Rail fuse < main fuse so a rail fault trips locally. | [Amazon search: "Blue Sea ST blade fuse block"](https://www.amazon.com/s?k=Blue+Sea+ST+blade+fuse+block) |
| 1 | **6 V power distribution bus bar (100 A dual-stud)** | Distribute regulated 6 V to the per-rail feeds and inject V+ into **both** PCA9685 boards with adequate gauge. **Never run all rail current through one PCA screw terminal** — that burned a board's V+ trace (9.8 V in, 0.5 V at the header). | [Amazon search: "12v 100A bus bar M6 stud"](https://www.amazon.com/s?k=12v+100A+bus+bar+M6+stud) |
| 1 | **12 AWG silicone wire (red + black)** | Main LiPo lead + regulator feeds (~15–22 A). Fine-strand silicone flexes and takes heat. | [Amazon search: "12 AWG silicone wire red black"](https://www.amazon.com/s?k=12+AWG+silicone+wire+red+black) |
| 1 | **14/16 AWG silicone wire (red + black)** | Per-rail 6 V feeds, gauge matched to each rail's fuse (14 AWG for 15 A rails, 16 AWG for 10 A rails). | [Amazon search: "14 16 AWG silicone wire"](https://www.amazon.com/s?k=14+16+AWG+silicone+wire) |
| 1 | **Hardware e-stop: 30/40 A automotive relay + Arduino relay-driver module** | High-current cutoff on the 12 V feed to the regulators that **defaults OFF** at power-on/reset; the Arduino GPIO must actively arm it, and DISARM/E-STOP/watchdog opens it. The software disarm only stops PWM (firmware `X` = limp) — this removes **power**. Keep the manual anti-spark switch as the physical e-stop. | [Amazon search: "arduino relay module 30A automotive"](https://www.amazon.com/s?k=arduino+relay+module+30A+automotive) |
| 1 | **ACS758-050B current sensor** (+ optional INA226) | Isolated hall sensor on the main lead so firmware can read amps and **auto-DISARM + open the cutoff on overcurrent** (ties into the ARM/DISARM system). Optional INA226 I²C for per-rail digital amps — jumper its address OFF **0x40** (PCA9685 clash) to 0x44/0x45. See `POWER_SYSTEM.md` §9. | [Amazon search: "ACS758 current sensor 50A"](https://www.amazon.com/s?k=ACS758+current+sensor+50A) |
| 1 | **iSDT D2 / SkyRC B6 / HOTA D6 — any 3S balance charger** | Don't cheap out on charging — this is the fire-risk part of the build. | [Amazon search: "3S lipo balance charger"](https://www.amazon.com/s?k=3S+lipo+balance+charger) |
| 1 | **LiPo safety bag (medium)** | Charge AND store inside this. $8. | [Amazon search: "lipo safety bag fireproof"](https://www.amazon.com/s?k=lipo+safety+bag+fireproof) |
| 2 | **XT60 pigtail (M and F, with silicone wire)** | One on the battery cable, one to feed the BEC pair through a switch. | [Amazon search: "XT60 pigtail 12awg"](https://www.amazon.com/s?k=XT60+pigtail+12awg) |
| 1 | **Anti-spark on/off switch with XT60 ends** | Hard cut-off so you don't have to unplug the LiPo every time. The "anti-spark" variant has a precharge resistor so you don't pop the switch the first time you connect. | [Amazon search: "rc lipo anti-spark switch xt60"](https://www.amazon.com/s?k=rc+lipo+anti-spark+switch+xt60) |

### B.3 Control electronics

| Qty | Part | Why | Search link |
|---:|---|---|---|
| 1 | **Arduino Mega 2560 (ELEGOO R3 clone is fine)** | Servo-bridge firmware host.  Need 18 PWM channels + I²C bus. Mega has both. The Uno does *not* have enough hardware PWM, but you don't need hardware PWM because the PCA9685 is generating the PWM. Mounts onto the `electronics_tray` via 4 × M3 brass heat-set inserts + 4 × M3 × 8 mm SHCS (next two rows in §B.4); bolt pattern is the published Arduino Mega 2560 R3 footprint (2.54/15.24, 50.8/15.24, 7.62/66.04, 50.8/90.17 mm). | [Amazon search: "Arduino Mega 2560 R3"](https://www.amazon.com/s?k=Arduino+Mega+2560+R3) |
| 1 | **Raspberry Pi 4 Model B (or Pi 5)** | High-level brain: ROS 2 / Python gait planner + vision + Wi-Fi.  85 x 56 mm board mounts onto the `electronics_tray` via 4 × M2.5 brass heat-set inserts + 4 × M2.5 × 8 mm SHCS (rows in §B.4); the Pi's standard 49 x 58 mm 4-hole pattern fits the tray's `PI_HOLES` bosses 1:1.  Pi 5 has the same mounting footprint; choose either. | [Amazon search: "Raspberry Pi 4 Model B 4GB"](https://www.amazon.com/s?k=Raspberry+Pi+4+Model+B+4GB) |
| 2 | **PCA9685 16-channel 12-bit PWM driver (I²C)** | Two boards, daisy-chained, give you 32 PWM lines. Adafruit-clone listings are typically $4–6 each. **Both** PCA9685s bolt to the `electronics_tray` via 4 × M3 heat-set inserts + 4 × M3 × 8 mm SHCS each (8 of each total — see §B.4); the secondary daisy-chains over I²C at address 0x41 (jumper). | [Amazon search: "PCA9685 16 channel servo driver"](https://www.amazon.com/s?k=PCA9685+16+channel+servo+driver) |
| 1 | **MPU-6050 IMU breakout (GY-521)** | Closed-loop body-attitude control: 3-axis gyro + 3-axis accelerometer over I²C.  PCB is ~ 21.2 × 16.4 × 1.6 mm with 4 × Φ 3.0 mm holes on a 15 × 11 mm pattern; bolts to `imu_pad.stl` via 4 × M3 × 8 SHCS into M3 brass heat-set inserts.  The pad mounts foam-taped to chassis_top centre (NOT to the electronics_tray — see PROTOTYPE.md §"IMU mount"). | [Amazon search: "MPU-6050 GY-521 module"](https://www.amazon.com/s?k=MPU-6050+GY-521+module) |
| 1 | **Servo extension cables, 30 cm, 3-pin male-female, pack of 20** | The DS3225 stock pigtails are ~ 30 cm and most of the 18 joints reach the PCA on stock pigtail alone; the remainder need ONE 30 cm extension to reach the +X-half PCAs.  The BOM auto-generated by `python -m hexapod_walker.prototype.pi_control.wire_harness_plan` is the source of truth.  As of the May 2026 chassis_bottom-integrated yaw cradle redesign the per-leg yaw run shortened by ~ 62 mm of Manhattan distance (the wire-exit corridor moved from the cradle's +X face to its -X face, putting the harness mouth right next to the leg drop slot), so a few of the previously-required yaw extensions are no longer needed -- re-derive the count from the harness plan output before ordering.  The 20-pack is the cheapest stocking unit and leaves headroom either way. | [Amazon search: "servo extension cable 30cm 20 pack"](https://www.amazon.com/s?k=servo+extension+cable+30cm+20+pack) |
| 1 | **Nylon zip-ties, 2-3 mm wide x ~ 100 mm long, 100-pack** | 4 per leg = 24 used for harness strain relief: one at each cradle's printed `cable_zip_post` (yaw / hip / knee = 3 per leg) plus one looped through each leg's `chassis_bottom` cable drop slot per leg (each leg's cable drop slot doubles as the zip-tie anchor -- pass a zip-tie through the slot to bundle the per-leg harness).  Plus a few extras for tidying up the inter-plate cable runs.  A standard 100-pack is far more than enough. | [Amazon search: "nylon zip ties 4 inch 100 pack"](https://www.amazon.com/s?k=nylon+zip+ties+4+inch+100+pack) |
| 1 | **Dupont jumper wire kit (M-F, F-F, M-M, 20 cm)** | I²C, power, IMU wiring. | [Amazon search: "dupont jumper wires 120 pcs"](https://www.amazon.com/s?k=dupont+jumper+wires+120+pcs) |
| 1 | **Heat-shrink assortment** | Power-side wiring tidy-up. | [Amazon search: "heat shrink tubing assorted"](https://www.amazon.com/s?k=heat+shrink+tubing+assorted) |
| 1 | **USB-A → USB-B cable, 6 ft** | Programming the Mega. | [Amazon search: "USB A to B cable Arduino"](https://www.amazon.com/s?k=USB+A+to+B+cable+Arduino) |
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

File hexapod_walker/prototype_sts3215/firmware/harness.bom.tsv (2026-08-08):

Id | Description | Qty | Unit | Designators
1 | Cable, 1 x 12 AWG | 0.4 | m | W_TRUNK_FUSED, W_TRUNK_GND, W_TRUNK_VPLUS
2 | Cable, 1 x 22 AWG | 0.1 | m | W_GND_BOND
3 | Cable, 2 x 12 AWG | 0.15 | m | W_TRUNK_LIPO
4 | Cable, 2 x 16 AWG | 1.34 | m | W_BR_L0, W_BR_L1, W_BR_L2, W_BR_L3, W_BR_L4, W_BR_L5, W_PWR_L0, W_PWR_L1, W_PWR_L2, W_PWR_L3, W_PWR_L4, W_PWR_L5
5 | Cable, 2 x 20 AWG | 0.25 | m | W_UNOQ_TAP
6 | Cable, 2 x 24 AWG | 1.8 | m | W_BUS_HEAD, W_DATA_L0L1, W_DATA_L1L2, W_DATA_L2L3, W_DATA_L3L4, W_DATA_L4L5
7 | Cable, 3 x 22 AWG | 3.6 | m | W_CHAIN_L0A, W_CHAIN_L0B, W_CHAIN_L1A, W_CHAIN_L1B, W_CHAIN_L2A, W_CHAIN_L2B, W_CHAIN_L3A, W_CHAIN_L3B, W_CHAIN_L4A, W_CHAIN_L4B, W_CHAIN_L5A, W_CHAIN_L5B
8 | Cable, 4 x 28 AWG | 0.15 | m | W_I2C
9 | Connector, 3S LiPo (11.1 V nom), XT60 female, 2 pins | 1 |  | LIPO
10 | Connector, Anti-spark switch, XT60 in/out, 4 pins | 1 |  | SWITCH
11 | Connector, Arduino Uno Q, 6 pins | 1 |  | UNOQ
12 | Connector, Central trunk pair (2x 5-port Wago 221-415), 15 pins | 1 |  | TRUNK_WAGO
13 | Connector, FEETECH STS3215, Molex 5264 3-pin, 3 pins | 18 |  | SERVO10, SERVO11, SERVO12, SERVO13, SERVO14, SERVO15, SERVO16, SERVO17, SERVO18, SERVO19, SERVO2, SERVO3, SERVO4, SERVO5, SERVO6, SERVO7, SERVO8, SERVO9
14 | Connector, GY-521 (MPU-6050), 4 pins | 1 |  | IMU
15 | Connector, Main fuse 15-20 A, blade/ANL in holder, 2 pins | 1 |  | FUSE
16 | Connector, Molex 5264 pigtail, crimped 3-pin, 3 pins | 6 |  | L0_INJ, L1_INJ, L2_INJ, L3_INJ, L4_INJ, L5_INJ
17 | Connector, Power Wago pair (2x Wago 221-413), 2 pins | 6 |  | L0_WAGO, L1_WAGO, L2_WAGO, L3_WAGO, L4_WAGO, L5_WAGO
18 | Connector, USB bus-servo adapter, FE-URT-2 / Waveshare A, 3 pins | 1 |  | ADAPTER
19 | Wire, BK | 0.3 | m | W_USB

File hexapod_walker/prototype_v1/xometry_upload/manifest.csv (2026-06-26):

filename | qty | material | color | finish | envelope_x_mm | envelope_y_mm | envelope_z_mm | volume_cm3_per_part | volume_cm3_total | notes
chassis_top.stl | 1 | MJF PA12 | white | as-printed | 140.0 | 161.7 | 7.0 | 67.61 | 67.61 | Top deck (140 mm flat-to-flat hex). Carries battery + electronics + optional arm; smaller than bottom so the legs sweep clear.
chassis_bottom.stl | 1 | MJF PA12 | white | as-printed | 226.1 | 242.0 | 15.0 | 193.39 | 193.39 | Bottom structural plate (200 mm flat-to-flat hex). Takes the six coxa-bracket M3 bolts and per-leg yaw-servo body cutouts.
battery_holder.stl | 1 | MJF PA12 | white | as-printed | 110.0 | 60.0 | 28.0 | 15.84 | 15.84 | Open-top LiPo tray; velcro slots through the long walls.
electronics_tray.stl | 1 | MJF PA12 | white | as-printed | 160.0 | 137.0 | 8.0 | 67.03 | 67.03 | Mounts Arduino + 2x PCA9685; standoffs are part of the geometry.
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

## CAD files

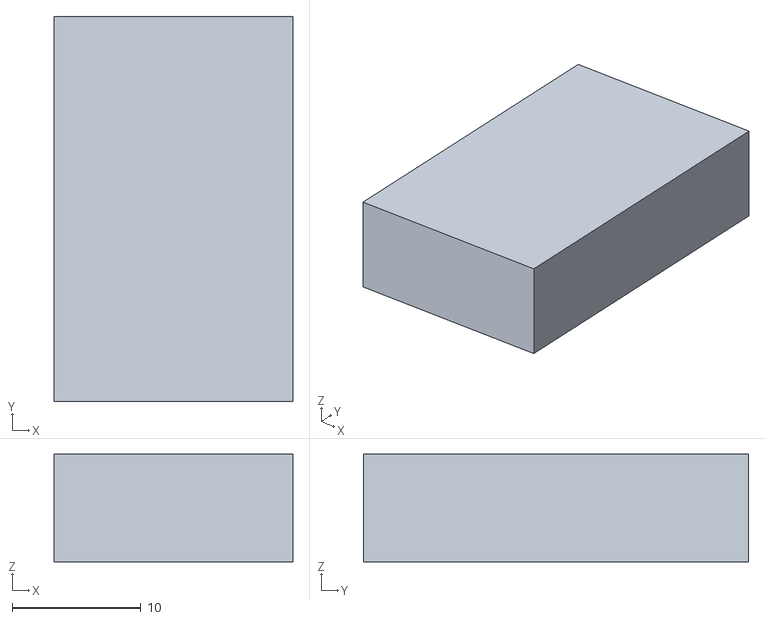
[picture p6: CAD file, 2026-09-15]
hexapod_walker/prototype_sts3215/mesh_mujoco/assets/wago_trunk.stl
18.6 x 30.0 x 8.40

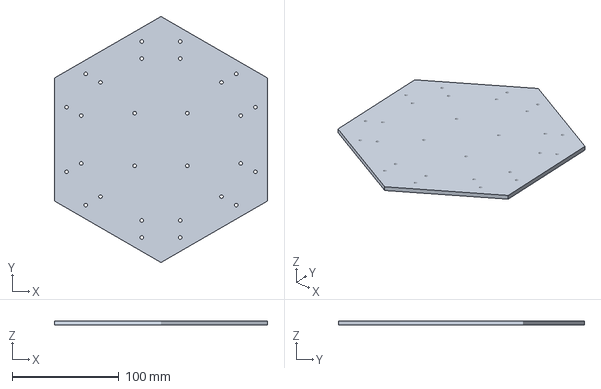
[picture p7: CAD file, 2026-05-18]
hexapod_walker/prototype_v1/bambu_h2d_trays/plate_01_chassis_plate_a.3mf
200.0 x 230.9 x 4.00 mm

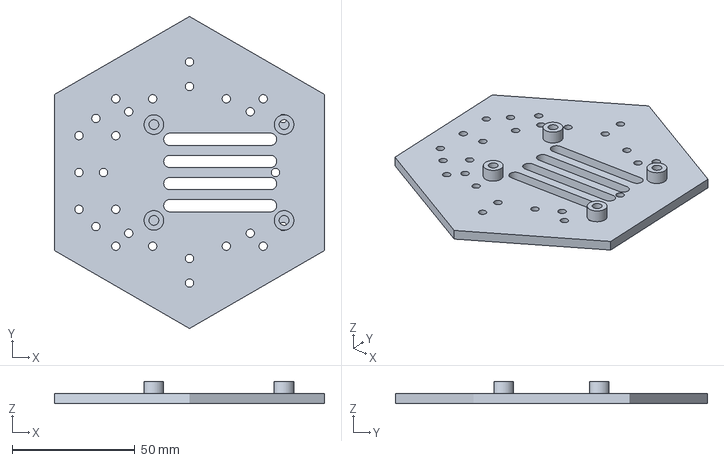
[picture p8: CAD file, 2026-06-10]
hexapod_walker/prototype_v1/bambu_tooling_plate/tooling_plate_buck.3mf
110.0 x 127.0 x 9.00 mm

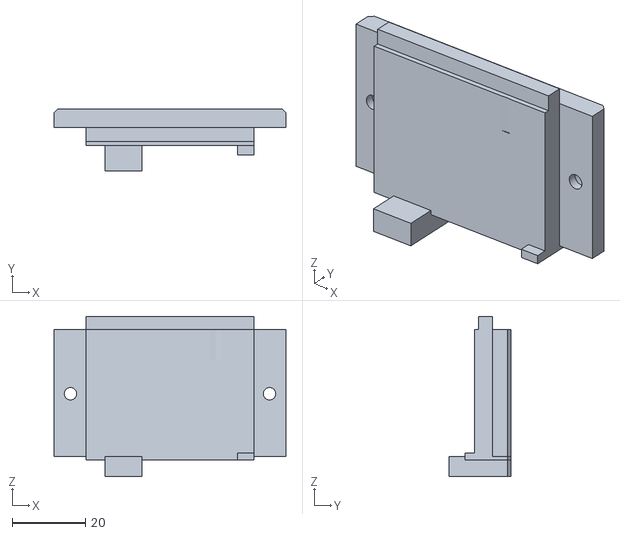
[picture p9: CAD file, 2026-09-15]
hexapod_walker/prototype_sts3215/mesh_mujoco/assets/knee_clamp_cap.stl
63.4 x 16.9 x 43.8

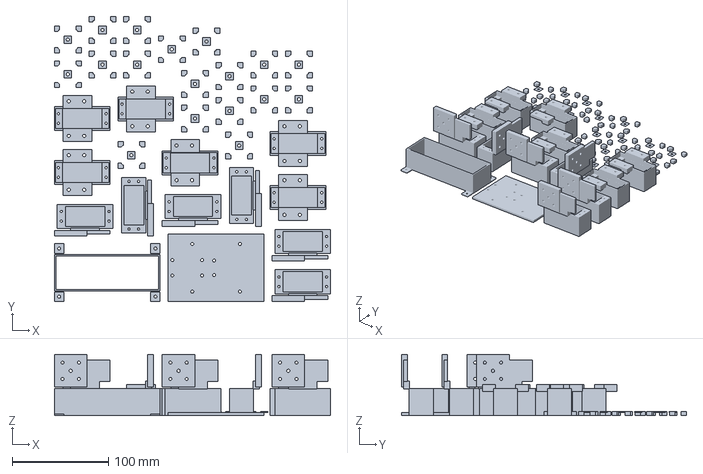
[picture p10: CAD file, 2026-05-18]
hexapod_walker/prototype_v1/bambu_h2d_trays/plate_04_rigid_hardware.3mf
287.0 x 296.0 x 63.5 mm

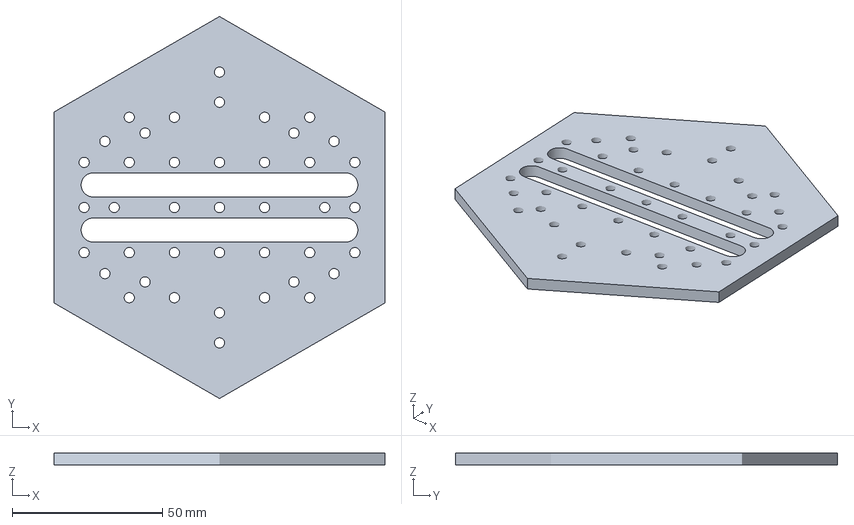
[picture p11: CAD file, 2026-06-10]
hexapod_walker/prototype_v1/bambu_tooling_plate/tooling_plate.3mf
110.0 x 127.0 x 4.00 mm

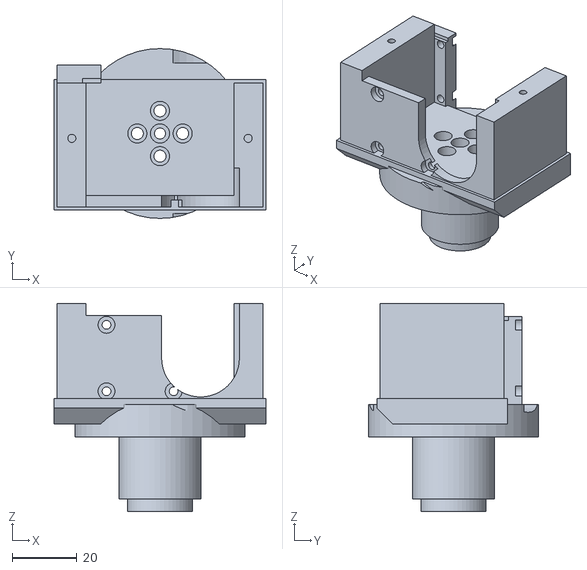
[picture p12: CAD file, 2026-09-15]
hexapod_walker/prototype_sts3215/mesh_mujoco/assets/coxa_link.stl
65.4 x 52.4 x 64.3

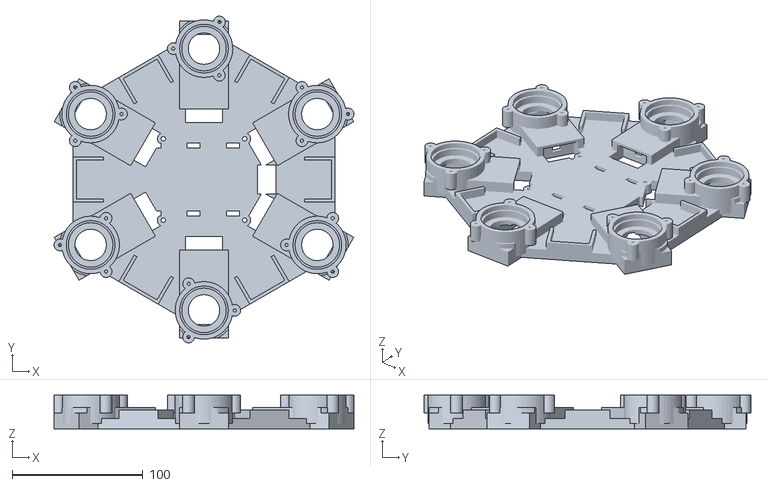
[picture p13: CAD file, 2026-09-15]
hexapod_walker/prototype_sts3215/mesh_mujoco/assets/chassis_bottom.stl
229.2 x 249.7 x 25.8

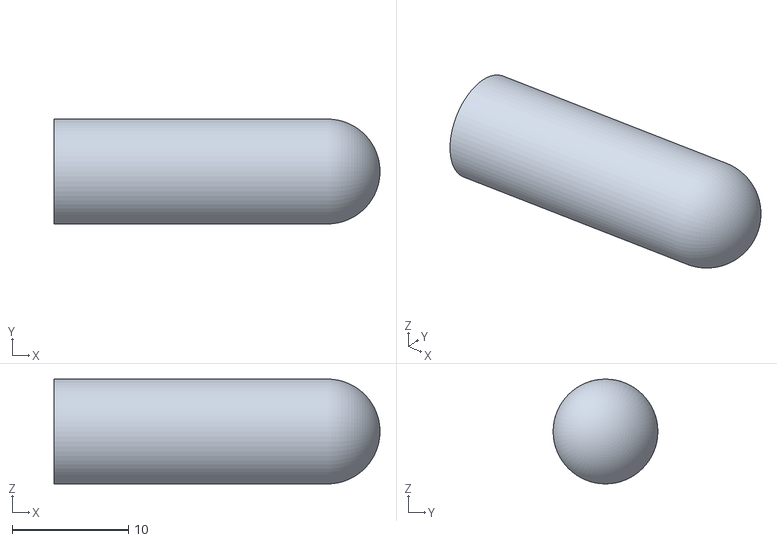
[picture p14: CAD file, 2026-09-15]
hexapod_walker/prototype_sts3215/mesh_mujoco/assets/foot_boot.stl
28.0 x 9.00 x 9.00

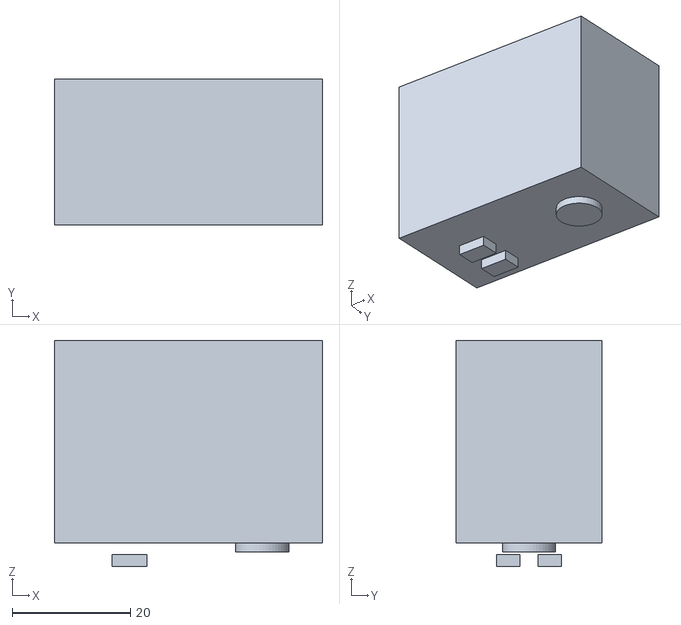
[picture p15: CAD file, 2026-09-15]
hexapod_walker/prototype_sts3215/mesh_mujoco/assets/knee_servo.stl
45.4 x 24.8 x 38.3

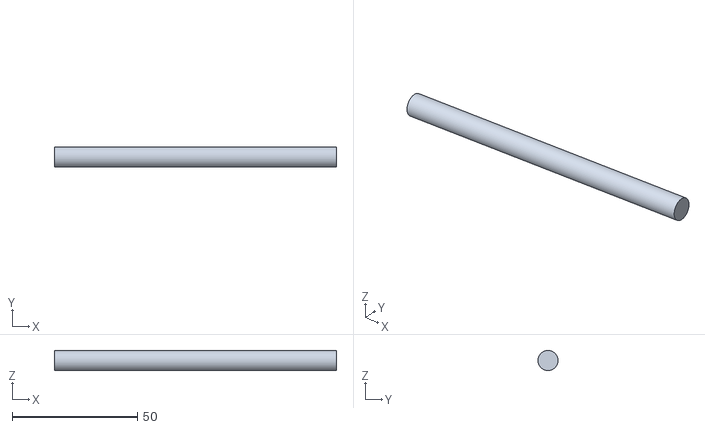
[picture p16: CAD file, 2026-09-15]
hexapod_walker/prototype_sts3215/mesh_mujoco/assets/tibia_tube.stl
112.5 x 8.00 x 8.00

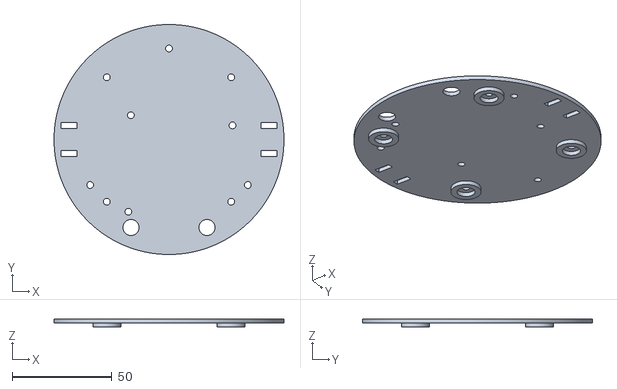
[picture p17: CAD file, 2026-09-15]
hexapod_walker/prototype_sts3215/mesh_mujoco/assets/hex_mount_plate.stl
115.0 x 115.0 x 4.00

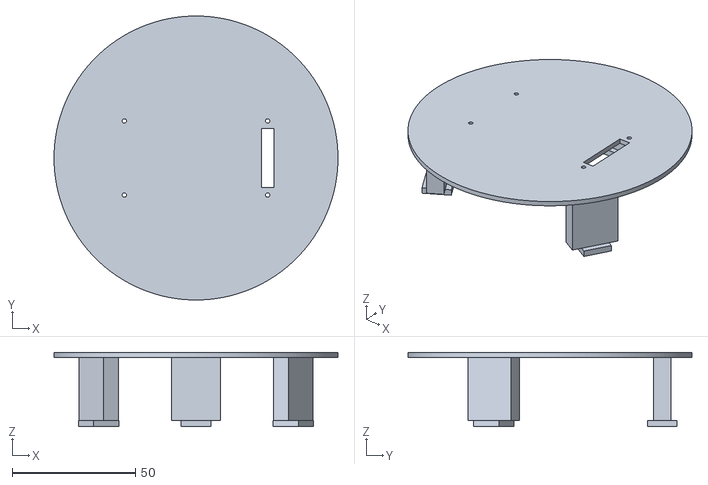
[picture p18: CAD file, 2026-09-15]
hexapod_walker/prototype_sts3215/mesh_mujoco/assets/hex_raised_platform.stl
115.0 x 115.0 x 30.0

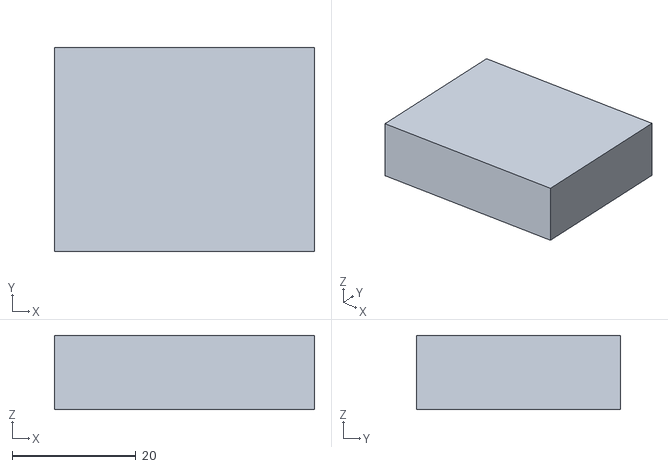
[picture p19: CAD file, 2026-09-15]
hexapod_walker/prototype_sts3215/mesh_mujoco/assets/motor_controller.stl
42.0 x 33.0 x 12.0

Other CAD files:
hexapod_walker/prototype_sts3215/mesh_mujoco/assets/femur_link.stl
hexapod_walker/prototype_sts3215/mesh_mujoco/assets/hex_post_standoff.stl
hexapod_walker/prototype_sts3215/mesh_mujoco/assets/breakout.stl
hexapod_walker/prototype_sts3215/mesh_mujoco/assets/chassis_standoff.stl
hexapod_walker/prototype_sts3215/mesh_mujoco/assets/chassis_top.stl
hexapod_walker/prototype_sts3215/mesh_mujoco/assets/disc_horn.stl
hexapod_walker/prototype_sts3215/mesh_mujoco/assets/hex_post_magnet.stl
hexapod_walker/prototype_sts3215/mesh_mujoco/assets/hex_post_thumb_nut.stl
hexapod_walker/prototype_sts3215/mesh_mujoco/assets/lipo_battery.stl
hexapod_walker/prototype_sts3215/mesh_mujoco/assets/mpu6050.stl
hexapod_walker/prototype_sts3215/mesh_mujoco/assets/screen.stl
hexapod_walker/prototype_sts3215/mesh_mujoco/assets/switch_holster.stl
hexapod_walker/prototype_sts3215/mesh_mujoco/assets/tibia_knee_yoke.stl
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

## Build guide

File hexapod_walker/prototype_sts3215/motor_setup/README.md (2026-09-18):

# `motor_setup/` — STS3215 bus bring-up + control

Everything that talks to the FEETECH STS3215 bus from a laptop (URT-2)
or the Arduino Uno Q lives here. Formerly split across `pi_control` /
`host` / `test_setup`.

| File | Role |
|---|---|
| `urt2_motor_setup.py` | Name / heal / test / zero-pose wizard |
| `feetech_bus.py` | STS bus driver + CLI (`scan`, `stance`, `hold`, …) |
| `urt2_bench.py` | Shared bench helpers (heal, identity, abort) |
| `inplace_demos.py` | Demos (wave / rise) + motion telemetry |
| `motion_telemetry.py` | CSV logger / shake diagnosis |
| `wire_harness_plan.py` | Cable length model |

Named servo IDs live on the robot in `~/.local/share/hexapod/motor_setup_registry.json`
(`registry.py`); nothing in this directory or the deploy bundle is a registry.
Replacing one servo through the running robot API: `linux_control/motor_swap.py`.

```bash
cd hexapod_walker/prototype_sts3215/motor_setup
python urt2_motor_setup.py
python inplace_demos.py --demo shimmy
python feetech_bus.py scan
```

To run the same wizard **on the Uno Q** (this directory deploys to the
board as part of `linux_control/deploy_ssh.sh` / `deploy_adb.sh`):

```bash
# on board:  cd ~/hexapod_sts/motor_setup && ./run.sh
```

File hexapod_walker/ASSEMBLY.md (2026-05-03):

# Human-Carrying Hexapod Walker — Build Guide

> This guide describes a one-rider, six-legged walking vehicle assembled
> from the STL parts produced by [`hexapod_walker.py`](hexapod_walker.py),
> 18 industrial harmonic-drive servomotors, an aluminium-extrusion leg
> structure, and a 96 V LiFePO₄ battery system. Top speed at completion
> is a brisk crawl (~ 0.4 m/s); payload is one rider up to 110 kg.
>
> **This is a serious, large-scale project.** A finished walker masses
> ~ 280 kg (vehicle) + rider, draws kilowatts, and can pinch fingers in
> ways that do not heal. Read the [Safety](#11-safety) section first.

---

## 1. The big idea

The vehicle is six identical legs spaced 60 ° around a regular hexagonal
chassis. Each leg has the same three-DOF kinematic chain found in a real
spider or insect:

```
    chassis edge --( yaw )-- coxa --( pitch )-- femur --( pitch )-- tibia --|--- foot
                hip-yaw                  hip-pitch              knee-pitch
```

So the full vehicle has **6 × 3 = 18 actuators**.

Two design choices collapse most of the build complexity:

1. **All 18 joints use the *same* actuator part number.** Pick one
   harmonic-drive servomotor with enough torque for the worst joint
   (knee at full extension) and use it everywhere. You replace 18
   parts from one bin instead of three. Spares are a single SKU.
2. **All six legs are *mechanically identical*.** The same five STLs
   (`coxa_bracket`, `coxa_link`, `femur_link`, `tibia_link`, `foot_pad`)
   plus three motors per leg — multiplied by six — make up everything
   below the chassis. The chassis and saddle/electronics stack are
   one-offs.

The walker is a tripod-gait machine: at any instant three legs
(alternating triangles) are planted on the ground while the other
three lift, swing forward, and replant. This is statically stable
in both half-cycles, so the vehicle stays upright even if all power
fails.

---

## 2. Final specification at a glance

| Property | Value |
|---|---|
| Configuration | 6 legs × 3 DOF, alternating-tripod gait |
| Overall envelope (foot-to-foot, fully extended) | ~ 4.0 × 4.5 × 1.2 m |
| Standing height (rider seat) | ~ 1.3 m |
| Stride length | ~ 0.6 m |
| Cruise speed (tripod gait) | ~ 0.4 m/s (1.4 km/h, brisk crawl) |
| Climb capability | ~ 25 ° slope, 200 mm step |
| Vehicle dry mass | ~ 280 kg |
| Payload | 1 rider, ≤ 110 kg |
| Total mass on the ground | ~ 390 kg |
| Per-leg static load (tripod stance) | ~ 1.27 kN (130 kg) |
| Peak knee torque | ~ 770 N·m |
| Peak hip-pitch torque | ~ 1.4 kN·m |
| Battery | 2 × 48 V 50 Ah LiFePO₄ in series → 96 V 50 Ah |
| Continuous draw (cruise) | ~ 1.6 kW |
| Range, level ground | ~ 2 hours / ~ 3 km |
| Mounting | Step-up footrest on the +X side; rider faces +X |

Total build cost (typical, 2026 USD): **$45,000 – $110,000.** See §10.

---

## 3. STL files in `stl/`

Run `./run.sh hexapod_walker/hexapod_walker.py` to (re)generate every
file. All dimensions are in millimetres. All STLs are watertight
manifolds suitable for CAM, casting investment, or 3D-printing slicers.

### 3.1 Body parts (one of each)

| File | Envelope | Function |
|---|---|---|
| `chassis_hex.stl` | 1461 × 1344 × 121 mm | Welded square-tube hexagonal frame. The CAD models the 80 × 80 mm tubes as solid (~ 55 L); the *real* fabricated chassis uses 80 × 80 × 6 mm wall tube and weighs ~ 35 kg. Six bolt pads on the outer edges carry the hip-yaw motor brackets. |
| `chassis_top_deck.stl` | 1200 × 1386 × 12 mm | 12 mm 6061-T6 aluminum hex plate. CNC-cut from a single sheet. Lightening holes pre-drilled. Bolts to the top of `chassis_hex.stl`. |
| `saddle_mount.stl` | 320 × 220 × 238 mm | Vertical post (40 mm OD) + horizontal saddle plate. Accepts a standard motorcycle / bicycle suspension seatpost or a Crashbox-style harness. |
| `battery_box.stl` | 480 × 320 × 220 mm | Welded-aluminum or 3D-printed (Onyx/PA12-CF) box that holds two 48 V × 50 Ah LiFePO₄ packs in series. Open top — bolt-on lid is fabricated separately from a flat plate. |
| `electronics_bay.stl` | 360 × 240 × 140 mm | Sealed enclosure for the main controller, IMU, power-distribution PCB, and 18 motor-driver harnesses (cable glands modelled). |

### 3.2 Per-leg parts (print/cast 6 of each)

Each leg uses one of every part below, plus three motors. See §4 for a
manifest.

| File | Envelope | Function |
|---|---|---|
| `coxa_bracket.stl` | 210 × 224 × 220 mm | Bolts to the chassis edge bolt pad. Cradles the **hip-yaw motor**: motor body sits in the bottom plate, output flange points up. |
| `coxa_link.stl` | 320 × 130 × 210 mm | Rotates with the hip-yaw output. Carries the **hip-pitch motor** on a flat plate hanging off the arm's tangential side, axis perpendicular to the arm. |
| `femur_link.stl` | 810 × 109 × 210 mm | Thigh segment between hip-pitch output and knee-pitch motor. Box-section profile with 5 lightening holes. Hip plate clamps to the hip-pitch output flange (joint axis tangential); knee plate cradles the knee-pitch motor body. |
| `tibia_link.stl` | 954 × 107 × 210 mm | Shin segment. Knee plate clamps to the knee output flange (joint axis tangential, parallel to the hip-pitch axis — both legs swing in a single vertical plane); foot-side socket bolts to `foot_pad.stl` with 4 × M10. |
| `foot_pad.stl` | 220 × 220 × 94 mm | Compliant ground pad. The CAD STL is the **mould pattern** — the production part is cast 60-A urethane around a 6 mm steel disc with a moulded toe spike. |

> **Joint-axis convention.**  All hip-pitch and knee-pitch axes are
> parallel and run **tangential to the chassis** (perpendicular to the
> leg's outboard direction).  The motors hang on the leg's tangential
> side; their output flanges sit in the joint plane, and the femur /
> tibia spars run perpendicular to the joint axis.  This is the same
> kinematic topology as Spot, ANYmal, and most modern legged robots:
> two parallel pitch axes give a planar leg that can lift, swing, and
> plant in a single vertical plane.

### 3.3 Generic motor adapter (print 18 + spares)

| File | Envelope | Function |
|---|---|---|
| `motor_flange.stl` | 200 × 200 × 20 mm | Universal D = 200 mm flange-mount adapter ring with the 8 × M8 motor bolt circle and a 4-tab outer pattern. **Print/CNC 18** to mount each motor body to its host bracket. |

### 3.4 Visualization

| File | Envelope | Function |
|---|---|---|
| `assembly_preview.stl` | 3.95 × 4.52 × 1.14 m | All 1 + 1 + 1 + 1 + 1 + 6×5 + 1 = 35 parts placed in standing pose for visual sanity-checking. Not watertight — purely for visualization in MeshLab / Blender / Cursor's STL preview. |

---

## 4. Bill of materials

Quantities below are for **one walker, with 10 % overage on every
fastener and consumable** so a dropped bolt doesn't stop the build.
All prices are mid-2026 USD, order of magnitude only. Industrial
servomotors and batteries dominate the budget.

> Conventions used throughout this section:
> *  **SHCS** = socket-head cap screw (Allen-key drive).
> *  **A2-70** = 18-8 stainless, 700 MPa proof — fine for non-loaded
>    cosmetic / cover hardware.
> *  **10.9 ZP** = grade 10.9 alloy steel, zinc-plated — required for
>    every load-path bolt (motor mounts, coxa→chassis, foot mounts,
>    extrusion clamps).
> *  Torques are for **dry, clean threads with one drop of medium
>    threadlocker (Loctite 243)**. Reduce 25 % if you use anti-seize
>    instead.

### 4.1 Actuators (the expensive bit)

You need **18 servomotors of one part number.** The worst-loaded joint
is the hip-pitch at full extension, which sees ~ 1.4 kN·m peak.
Candidates (any one will work, listed by torque):

| Vendor | Model | Cont. torque | Peak torque | Price/each | Notes |
|---|---|---|---|---|---|
| Harmonic Drive | FHA-40C-100 | 740 N·m | 1.5 kN·m | $6 – 8 k | Pricey but bullet-proof. Hits the spec on hip joints with margin. |
| MyActuator | RMD-X12-150 | 350 N·m | 700 N·m | $1.8 – 2.5 k | Cheaper, lighter; OK at the knee, marginal at the hip — use 2 × per hip-pitch in a parallel-output gearbox if you must. |
| CubeMars | AK80-64 | 25 N·m | 120 N·m | $0.7 – 1 k | **Too small** by a factor of 10 for human carry; listed only so you don't accidentally pick one. |
| Custom | 6 kW BLDC + 1 : 80 cycloidal reducer | 600 N·m | 1.2 kN·m | $1.5 – 3 k DIY | The cost-effective DIY route. See §6.4. |

**Recommended:** 18 × Harmonic Drive **FHA-40C-100** with built-in
encoder + brake, controlled over EtherCAT.

> Whatever you pick, make sure the *flange OD ≤ 170 mm*, *bolt-circle
> diameter = 150 mm*, *output OD ≈ 100 mm*, and *axial length ≤ 130 mm*
> so it bolts straight into the geometry the STLs expect. If your motor
> deviates from those dimensions, edit the `MOTOR_*` constants near the
> top of `hexapod_walker.py` and re-run the generator.

### 4.2 Master fastener BOM

Every bolt the walker needs, counted from the STL bolt-hole patterns
plus the structural fab steps. **Buy each line at the listed quantity
(includes ~10 % overage).** Lengths are conservative — verify against
your actual extrusion thickness and motor flange depth before final
ordering.

| ID | Fastener | Grade | Use | Per-walker qty |
|---|---|---|---|---|
| **F1** | M8 × 30 mm SHCS | 10.9 ZP | Motor body & motor output flange to bracket / link end-cap (8 holes per joint face × 2 faces × 18 motors) | **320** |
| **F2** | M8 split-lock washer | Steel | One under every F1 head | **320** |
| **F3** | M10 × 90 mm SHCS, full thread | 10.9 ZP | Coxa bracket → chassis edge pad (4 per leg × 6) | **30** |
| **F4** | M10 nyloc nut, flanged | 10.9 ZP | Mate for F3 | **30** |
| **F5** | M10 flat washer (2 mm thick, OD 22) | Steel | Two per F3 (one each side) | **60** |
| **F6** | M10 × 50 mm SHCS | 10.9 ZP | Foot pad → tibia (4 per leg × 6) | **30** |
| **F7** | M10 × 120 mm SHCS, full thread | 10.9 ZP | Femur / tibia extrusion → end caps (4 per cap × 4 caps per leg × 6) | **110** |
| **F8** | M10 nyloc nut | 10.9 ZP | Mate for F7 | **110** |
| **F9** | M10 flat washer | Steel | Two per F7 | **220** |
| **F10** | M8 × 25 mm SHCS | A2-70 | Top deck → chassis (12), battery box → top deck (4), electronics bay → top deck (4) | **25** |
| **F10b** | M8 rivnut, knurled, ribbed shank, alu/steel | Steel | Installed in the **top wall of every chassis tube + every top-deck deck mount point** so F10 has something to thread into without internal access | **25** |
| **F11** | M8 nyloc nut | A2-70 | Reserved for accessories where there *is* underside access (none in the standard build) | **5** |
| **F12** | M10 × 25 mm SHCS | A2-70 | Saddle mount base → chassis hub (4) | **5** |
| **F13** | M6 × 16 mm SHCS | A2-70 | Cable carrier mounts (2 ends × 2 bolts per end × 18 carriers = 72) | **80** |
| **F14** | M6 × 20 mm SHCS | A2-70 | Pinch-point decals, harness anchors, misc cable-tie mount points | **30** |
| **F15** | M5 × 16 mm SHCS | A2-70 | Battery box lid (12), electronics bay lid (8), internal BMS / contactor mount (16), foot load cell sandwich (4 × 6 = 24) | **70** |
| **F16** | M5 nyloc nut | A2-70 | Mate for F15 (used inside electronics bay) | **20** |
| **F17** | M3 × 8 mm self-tapper | Steel | IMU, foot load cells, status LEDs | **30** |
| **F18** | M12 × 1.75 footrest stud (welded to top deck) | 8.8 ZP | Rider footpegs | **2** |

> **Total tally** (rounded to box quantities you can buy on one
> Misumi / McMaster cart): 320 × M8 × 30, 25 × M8 × 25, 25 × M8
> rivnuts, 30 × M10 × 90, 30 × M10 × 50, 110 × M10 × 120, 5 × M10 ×
> 25, 80 × M6 × 16, 30 × M6 × 20, 70 × M5 × 16, 30 × M3 × 8.

### 4.3 Fastener detail by joint

A second view of the same hardware, this time grouped by *where it
goes* so you can lay out per-leg kits before assembly.

| Joint / interface | Fasteners | Length basis |
|---|---|---|
| **Coxa bracket → chassis edge pad** (×6) | 4 × F3 (M10 × 90) + 4 × F4 nyloc + 8 × F5 washer | through 18 mm bracket flange + 40 mm pad + nut clearance |
| **Yaw motor body → coxa bracket bottom plate** (×6) | 8 × F1 (M8 × 30) + 8 × F2 lock washer | thread into motor body's tapped flange |
| **Coxa link bottom hub → yaw motor output flange** (×6) | 8 × F1 + 8 × F2 | thread into motor output |
| **Hip-pitch motor body → coxa link pitch plate** (×6) | 8 × F1 + 8 × F2 | thread into motor body |
| **Femur hip plate → hip-pitch motor output flange** (×6) | 8 × F1 + 8 × F2 | thread into motor output |
| **Knee motor body → femur knee plate** (×6) | 8 × F1 + 8 × F2 | thread into motor body |
| **Tibia knee plate → knee motor output flange** (×6) | 8 × F1 + 8 × F2 | thread into motor output |
| **Foot pad → tibia foot hub** (×6) | 4 × F6 (M10 × 50) | thread into foot pad's embedded steel disc |
| **Femur extrusion → hip end cap** (×6) | 4 × F7 (M10 × 120) + 4 × F8 + 8 × F9 | through-bolt cap + 90 mm extrusion + cap |
| **Femur extrusion → knee end cap** (×6) | 4 × F7 + 4 × F8 + 8 × F9 | same |
| **Tibia extrusion → knee end cap** (×6) | 4 × F7 + 4 × F8 + 8 × F9 | through-bolt cap + 70 mm extrusion + cap |
| **Tibia extrusion → foot end cap** (×6) | 4 × F7 + 4 × F8 + 8 × F9 | same |
| **Top deck → chassis** | 12 × F10 (down through deck into 12 × F10b rivnuts in chassis top wall) | rivnut required because the chassis is a closed welded tube |
| **Saddle mount → chassis hub** | 4 × F12 (M10 × 25) | thread into 4 × tapped M10 holes in the centre hub disc (90 mm PCD) |
| **Battery box → top deck** | 4 × F10 (through box base into 4 × F10b rivnuts in top deck) | rivnut keeps the install one-sided |
| **Battery box lid** | 12 × F15 | thread into 12 × M5 weld-nuts on the box rim |
| **Electronics bay → top deck** | 4 × F10 (through bay base into 4 × F10b rivnuts in top deck) | same |
| **Electronics bay lid** | 8 × F15 | thread into bay rim |
| **Cable carrier mounts** | 72 × F13 (2 ends per carrier × 2 bolts per end × 18 carriers) | through carrier mount-plate into link |
| **Foot load-cell sandwich** (×6) | 4 × F15 (M5 × 16) per foot | 2 anchoring the load-cell foot end to a 60 × 30 × 2 mm 6061 sandwich plate, 2 anchoring the load-cell tibia end to the tibia foot hub bottom face |
| **Misc / decals / harness** | 30 × F14, 30 × F17, 2 × F18 | as required |

**Per-leg fastener sub-total (for kitting):** 48 × F1 (motor mounting),
4 × F3, 4 × F4, 8 × F5 (chassis), 4 × F6 (foot), 16 × F7 + 16 × F8 +
32 × F9 (extrusion clamps), 6 × F13 (cable carriers).

### 4.4 Torque schedule

| Fastener | Substrate | Torque (10.9 ZP, dry + Loctite 243) |
|---|---|---|
| M5 SHCS | aluminum or steel | **5 N·m**  (3.7 ft·lb) |
| M6 SHCS | aluminum or steel | **9 N·m**  (6.6 ft·lb) |
| M8 SHCS into FHA-40C flange | hardened steel motor body | **28 N·m**  (20.7 ft·lb) |
| M8 SHCS, A2-70, decorative | aluminum | **18 N·m**  (13.3 ft·lb) |
| M10 SHCS through-bolt + nyloc | steel pad / aluminum extrusion | **56 N·m**  (41 ft·lb) |
| M10 SHCS into tapped foot disc | hardened steel | **56 N·m** |
| M12 stud (footrest) | weld | weld pre-load only |

> Use a calibrated 0–60 N·m click-type torque wrench. **Tighten every
> 8-bolt motor flange in a star pattern** (1, 5, 3, 7, 2, 6, 4, 8) in
> three passes: 30 %, 70 %, 100 % of final torque.

### 4.5 Structural — leg extrusions

The femur and tibia STLs model a solid 90 × 120 (femur) and 70 × 90
(tibia) block. The **real** parts are hollow rectangular aluminium
extrusions (6061-T6) bolted into the printed/cast end caps. Buy:

| Part | Section | Length each | Wall | Qty | Notes |
|---|---|---|---|---|---|
| Femur extrusion | 90 × 120 × 6 mm wall | 480 mm | 6 mm | 6 | 6061-T6, mill-finish |
| Tibia extrusion | 70 × 90 × 5 mm wall | 690 mm | 5 mm | 6 | 6061-T6, mill-finish |

(`FEMUR_LENGTH` and `TIBIA_LENGTH` in `hexapod_walker.py` include the
length of the hubs at each end; the bare extrusion is shorter.)

> **Drilling the extrusions for F7:** match each end-cap's 4-hole
> pattern to the extrusion using a marking gauge, drill Φ 11 mm
> through both walls, deburr inside with a 90 ° countersink so the
> through-bolt seats square on the steel washer.

### 4.6 Structural — chassis & body plates

| Part | Spec | Qty |
|---|---|---|
| 80 × 80 × 6 mm wall sq. tube, 6063-T5 aluminum (or A36 mild steel) | 6 × 693 mm perimeter (30 ° mitres) + 6 × 380 mm spokes | 1 set |
| Centre hub disc, 12 mm 6061-T6 plate | 360 mm Ø, 4 × M10 tapped at 90 mm PCD (4 holes at 45 ° offsets, 45 mm radius) for saddle mount | 1 |
| Chassis edge pads, **40 × 200 × 112 mm**, 6061-T6 plate | Drilled 4 × Φ 11 mm at the 160 × 60 mm pattern from `chassis_hex.stl`, drilled radially through the 40 mm thickness | 6 |
| Top deck, 12 mm 6061-T6 plate | CNC-cut to `chassis_top_deck.stl` outline + 12 × Φ 9 mm mount holes | 1 |
| Battery box body, 4 mm 5052-H32 aluminum sheet | TIG-welded box per `battery_box.stl` | 1 |
| Battery box lid, 8 mm 6061-T6 plate | Drilled 12 × Φ 5.3 mm | 1 |
| Electronics bay body | 3 mm 5052 sheet, TIG-welded, IP-65 gaskets | 1 |

### 4.7 End-cap cast/printed parts (the STL files)

Six per per-leg STL plus one per body STL plus 18 universal flanges.
Two sourcing options:

* **CNC-machined 6061-T6 aluminum** (recommended for the load-bearing
  links: `coxa_bracket`, `coxa_link`, `femur_link`, `tibia_link`).
  Send the STL to a CNC shop (Xometry, PCBWay Mechanical, Protolabs,
  any local 3-axis aluminum shop). Expect $80 – $300 per part for
  CNC, $1,800 – $5,400 for the full link set × 6.

* **MJF or SLS PA12-CF nylon** (acceptable for `coxa_bracket`,
  `chassis_top_deck`, `saddle_mount`, `battery_box`,
  `electronics_bay`, `foot_pad` mould patterns, and the
  `motor_flange` adapters). $20 – $80 per part. The femur and
  tibia links should *not* be 3D-printed — the bending loads are too
  high. CNC them.

### 4.8 Battery system

| Part | Spec | Qty |
|---|---|---|
| LiFePO₄ pack | 48 V (16S) × 50 Ah / 2.4 kWh, with integrated 100 A BMS, M8 stud terminals | 2 |
| Inter-pack series link | 4 AWG (21 mm² Cu) tinned, double-crimp ring lugs (M8) | 1 (300 mm) |
| Series-link inline fuse | 100 A class-T fuse + holder | 1 |
| Main contactor | Tyco / TE EV200AAANA, 96 V DC, 500 A make / 2 kA break | 1 |
| Pre-charge resistor | 50 Ω, 50 W wire-wound | 1 |
| Pre-charge relay | 96 V DC coil, 5 A | 1 |
| E-stop button (handlebar) | DPST mushroom, latching, 10 A | 1 |
| Bus bleed LED + 100 kΩ resistor | green panel-mount, "BUS LIVE" | 1 |
| Power cable, controller side | 8 AWG silicone, 2 m | 2 m |
| Power cable, motor side | 12 AWG silicone, 18 × 2.5 m | 45 m |
| XT90 / Anderson SB175 main connector | as bus disconnect | 1 |
| Battery hold-down strap | 50 mm wide nylon, ratchet | 2 |

### 4.9 Motor controllers, compute, sensors

| Part | Spec | Qty |
|---|---|---|
| Motor drivers | 18 × matched to your motor (Elmo Gold Twitter for FHA, ODrive Pro v3 for the DIY route) | 18 |
| 24 V house battery | 24 V × 7 Ah AGM, for logic + brakes | 1 |
| 24 V → 12 V DC-DC | 200 W, for IPC fans / displays | 1 |
| Main controller | Industrial PC or NVIDIA Jetson Orin Nano, ROS 2 + EtherCAT master | 1 |
| 9-DOF IMU | Bosch BMI088 + magnetometer, e.g. VectorNav VN-100 | 1 |
| Foot force sensors | 200 kgf load cell per foot, e.g. SparkFun TAL220 | 6 |
| Foot load-cell sandwich plate | 60 × 30 × 2 mm 6061 (CNC scrap or hand-cut) | 6 |
| Foot load-cell amplifier | HX711 breakout | 6 |
| Joystick + small UI screen | Any USB joystick + 7" touchscreen | 1 |
| Status LEDs (RGB strip on top deck) | WS2812B, 60 LED/m, 1 m | 1 |

### 4.10 Wiring harness manifest

Cable lengths assume the controller + drive stack lives in the
`electronics_bay.stl` on the top deck (centre, +X side). Each cable
allows ~150 mm of slack at every joint for the cable carrier loop.

| Cable | Spec | Length each | Qty | Total |
|---|---|---|---|---|
| **Yaw motor power** | 12 AWG 4-conductor (3-phase + PE) shielded | 1.2 m | 6 | 7.2 m |
| **Hip-pitch motor power** | 12 AWG 4-conductor shielded | 1.8 m | 6 | 10.8 m |
| **Knee motor power** | 12 AWG 4-conductor shielded | 2.5 m | 6 | 15.0 m |
| **EtherCAT (M12 X-coded ↔ M12 X-coded)** | Cat-6A SF/UTP, 4-pair | 0.8 – 1.2 m | 18 | ~ 18 m |
| **24 V brake-release line, per joint** | 22 AWG twisted pair | 1.5 m | 18 | 27 m |
| **IMU cable** | RS-232 / USB, shielded | 1.5 m | 1 | 1.5 m |
| **Foot load cell** | 4-conductor + shield | 2.6 m (yes, all the way down to the foot) | 6 | 15.6 m |
| **Cable carrier** (igus E-chain or equivalent) | 30 mm × 50 mm cross-section, 90 ° rotation | 250 mm | 18 | 4.5 m |
| **PG-13.5 cable gland** | electronics bay outer wall | — | 7 | — |
| **PG-9 cable gland** | foot load-cell entry into tibia hub | — | 6 | — |
| **Heat-shrink, ¾"** | Black, 3 : 1 adhesive-lined | — | 5 m | — |
| **Insulated ring lugs, 8 AWG / M8** | for battery + contactor | — | 12 | — |
| **Insulated ring lugs, 12 AWG / M5** | for motor power | — | 144 (4/cable × 36) | — |
| **Heat-shrink ferrules, 12 AWG** | for driver-side terminations | — | 200 | — |
| **Spiral cable wrap, 25 mm** | Black, for trunk cable bundle | — | 4 m | — |

### 4.11 Saddle / rider attachment

| Part | Spec | Qty |
|---|---|---|
| Suspension seatpost | 30.9 / 31.6 mm, 100 mm travel | 1 |
| Bicycle / motorcycle saddle | Any | 1 |
| 4-point harness | Automotive 4-point | 1 |
| Footrests (rider's feet) | Off-the-shelf motorbike pegs welded to the top deck | 2 |
| High-vis decals & pinch-point stickers | Yellow vinyl, 50 mm | 24 |

### 4.12 Tools required

This is the *complete* kit for one builder. You can substitute
brand-equivalents but don't skip the torque wrench or the load-rated
hoist — both are critical for safety.

| Tool | Purpose | Notes |
|---|---|---|
| **Calibrated torque wrench, 5 – 60 N·m, 3/8" drive** | Every M5–M10 fastener | Click-type minimum; digital preferred |
| **Calibrated torque wrench, 20 – 200 N·m, 1/2" drive** | Reserve for chassis welds + lifting eyes (none in std build) | optional |
| **Allen / hex bit set, metric, ball-end, 3 – 10 mm** | All SHCS heads | 10.9 SHCS bit must be hardened |
| **Hex socket set, 8 – 17 mm, 3/8" drive** | Nyloc nuts | |
| **TIG welder + Ar gas + 4043 filler** | Chassis fab + battery box | Or job out per §6.1 |
| **Bandsaw or chop-saw with carbide blade** | Aluminum extrusion + tube | |
| **Drill press with cross-vise** | Chassis pad holes, extrusion through-holes | |
| **Step drill bits, Φ 9 + Φ 11** | M8 / M10 clearance | |
| **Tap set, M3 → M10, with handle** | Re-tap any blocked motor flange holes | |
| **Rivnut tool (handheld, M5 / M6 / M8 jaws)** | Setting F10b in chassis tube + top deck | Astro 1442 or equivalent |
| **Engine hoist or shop crane, 500 kg** | Lifting the chassis with all 6 legs (~ 220 kg) | Hire one for $50/day |
| **Hydraulic table lift, 1.2 m max, 300 kg cap.** | Sub-assembly bench | One welding-deck table works too |
| **Calibrated multimeter (CAT III 1000 V)** | Battery / contactor commissioning | Never skip |
| **DC clamp meter, 0 – 200 A** | Cruise-current measurements | |
| **Insulated screwdriver set (1000 V rated)** | Battery work | |
| **Crimp tool for ring lugs (8 AWG)** | Hammer-crimp or hydraulic | |
| **Crimp tool for ferrules (12 AWG)** | Ratcheting four-indent | |
| **Heat gun** | Heat-shrink termination | |
| **Cable cutter (8 AWG capable)** | Flush cuts for power cables | |
| **Marking gauge + scribe** | Hole transfer from STL → extrusion | |
| **Calipers, 200 mm, 0.01 mm** | Verify CNC parts on receipt | |
| **Spirit level, 600 mm, magnetic** | Chassis welding flatness | |
| **Pinch-point safety blocks (wood)** | Prop legs for service | 6 × 200 × 200 × 200 mm |
| **Saw-horses, 600 mm tall, 250 kg cap.** | Service stand for the walker | 4 |

### 4.13 Consumables

| Item | Spec | Qty |
|---|---|---|
| Loctite 243 (medium thread-locker) | Blue | 50 mL |
| Loctite 271 (high-strength thread-locker) | Red, only on F7 extrusion through-bolts | 50 mL |
| Anti-seize compound | Copper-based | 100 g tube |
| Dielectric grease | Silicone | 100 g tube |
| Cable ties, 200 mm × 4.8 mm UV-stable | Black | 200 |
| Adhesive cable-tie mounts | 25 mm sq | 50 |
| Self-fusing silicone tape, 25 mm | for connector strain relief | 1 roll |
| Powder-coat / paint, satin black | Chassis topcoat | 1 L |
| Etch primer | Pre-paint on bare aluminum | 0.5 L |
| Isopropyl alcohol, 99 % | Surface prep | 1 L |
| Lint-free wipes | Blue shop towel | 1 box |
| Latex gloves | Box of 100 | 2 boxes |
| Safety glasses | Polycarbonate | 2 |
| Welding shield + gloves | Auto-darkening | 1 set |
| First-aid kit | Standard 50-piece | 1 |
| Class C fire extinguisher | 5 lb minimum, lithium-rated if possible | 1 |

---

## 5. Mechanical design rationale

### 5.1 Leg-link length ratios

```
    coxa  : femur : tibia  =  150 : 600 : 800  mm
                           ≈  1   : 4   : 5
```

Two reasons for the long tibia:

1. **Knee torque is the limiting joint.** Knee torque scales linearly
   with the *horizontal* moment arm of the foot from the knee, which
   is dominated by tibia length × cos(tibia pitch). A long tibia
   working at a steep angle (knee folded, tibia near vertical) gives
   the same foot reach as a short tibia at a shallow angle, but with
   far less knee torque.
2. **Step height.** A long, near-vertical tibia at the knee can lift
   the foot up to ~ 250 mm clear of the ground in the swing phase
   without the femur having to pitch up dramatically — letting the
   walker step over typical ground obstacles.

### 5.2 Joint torque budget

Worst-case static (one-leg / fully-extended) loads:

```
    rider + vehicle  ≈  390 kg     →  3.83 kN total weight
    tripod gait shares this between 3 legs  →  1.27 kN per leg

    standing pose   femur pitch = -25°    tibia pitch (rel. femur) = +60°
                    => tibia is +35° below horizontal
                    => foot is 0.66 m horizontal + 0.46 m vertical from knee
                    => foot is 1.20 m horizontal from hip-pitch axis

    τ_knee  ≈  1.27 kN × 0.66 m   ≈    840 N·m   (+10 % shock = 920)
    τ_hip   ≈  1.27 kN × 1.20 m   ≈   1520 N·m   (+10 % shock = 1670)
    τ_yaw   ≈  20 N·m  (only friction + lateral imbalance — small)
```

Pick a motor with **continuous torque ≥ τ_max / 2** so it can sustain the
load indefinitely without thermal limits, and **peak torque ≥ 1.5 ×
τ_max** for the duty-cycle stride peaks. Either the FHA-40C-100 or a 6
kW BLDC + 80 : 1 cycloidal reducer comfortably hits this.

### 5.3 Weight breakdown

| System | Mass |
|---|---|
| Chassis (welded tube + top deck + pads) | ~ 35 kg |
| 6 × leg structural (femur + tibia + foot + brackets) | ~ 60 kg |
| 18 × motor + driver | ~ 130 kg (FHA-40C-100 is ~ 7 kg each) |
| Battery (2 × 48 V × 50 Ah LiFePO₄) | ~ 32 kg |
| Electronics, wiring, fasteners, paint | ~ 10 kg |
| Saddle + harness | ~ 8 kg |
| Hydraulics / soft parts (foot urethane) | ~ 5 kg |
| **Total dry** | **~ 280 kg** |
| Rider | + 110 kg max |
| **Total walking** | **≈ 390 kg** |

---

## 6. Manufacturing the parts

### 6.1 Chassis (welded square tube)

This is a manufacturing summary; for the bolt-by-bolt build sequence
see §8.2. Use 80 × 80 × 6 mm wall 6063-T5 aluminum or A36 mild steel:

1. Lay out a regular hexagon, flat-to-flat = 1200 mm, on a flat-deck
   welding table.
2. Cut **6 perimeter pieces to 693 mm** (the side length of a regular
   hexagon with 1200 mm flat-to-flat) with 30 ° mitres. Tack-weld
   into a hexagon.
3. Cut **6 spokes to 380 mm** (apothem 600 − hub radius 180 − 2 ×
   tube half-thickness 40). Tack weld each spoke from the centre hub
   disc out to the midpoint of each perimeter tube.
4. Insert and weld the **6 mounting pads** (cast or CNC-cut **40 ×
   200 × 112 mm** 6061-T6 plates) flush with the perimeter outboard
   face.
5. Drill the four Φ 11 mm M10 clearance holes through each pad in a
   **160 × 60 mm** pattern (`hexapod_walker.py` already cuts these
   holes in the STL — use it as a drill template).
6. Powder-coat or anodize.

Compare your finished welded chassis against `chassis_hex.stl` —
overall envelope and bolt-pad locations should match within ± 2 mm.

### 6.2 Femur and tibia links

These are the highest-stress parts on the vehicle. Don't print them.

1. Cut the aluminium extrusion to length (480 mm femur, 690 mm tibia
   — the rest of the STL length is the end caps).
2. CNC-machine the **end caps** from 6061-T6 plate, using
   `femur_link.stl` and `tibia_link.stl` as the input geometry. Each
   STL already includes the bolt-circle bores and clearance holes for
   the harmonic drive output flange.
3. Bolt the end caps to the extrusion with 4 × M10 through-bolts per
   end (or weld; bolting is preferred so the parts can be replaced
   after a fall).

### 6.3 Coxa bracket and coxa link

CNC from 6061-T6, or — for a more sculptural finish — investment-cast in
A356 aluminum (PCBWay Casting / Xometry / a local foundry will quote
from the STL directly). Min wall in the cast is 6 mm; the brackets are
modelled with 12 – 18 mm walls so they cast easily.

### 6.4 Cycloidal reducer (DIY motor route)

If you went with the cheap-motor route — 6 kW BLDC + cycloidal
reducer — you'll also need to fabricate the reducer. This is a
substantial mini-project on its own. See James Bruton's open-source
[CycloidDrive](https://github.com/XRobots/CycloidalDrive) repository or
the Skyentific MagicaCS series on YouTube.

### 6.5 Foot pad

The STL is the **mould pattern**, not the part. Production process:

1. 3D-print `foot_pad.stl` in PLA. Smooth with filler primer.
2. Wrap the printed pattern in 0.5 mm wax sheet.
3. Pour a 2-part silicone (e.g. Smooth-On Mold Star 30) around it in a
   wooden boxing.
4. Once cured, remove the pattern and pour the foot:
   * insert a 6 mm × 200 mm steel disc (CNC-cut, with **four
     M10 × 1.5 *tapped* holes** on the 36 × 36 mm pattern from
     `foot_pad.stl` — *not* clearance holes, the foot bolts F6
     thread directly into the disc from above),
   * pour 60-A urethane (Smooth-On VytaFlex 60) around it.
5. Demould after 24 h. Bolt to the tibia (see §8.3.3).

---

## 7. Electronics & control architecture

```
                   +-----------------------+
                   |  Controller (Jetson) |
                   |  ROS 2 / EtherCAT M  |
                   +-----------+----------+
                               |
                  EtherCAT or CAN bus (ring topology)
                               |
       +-------+-------+-------+-------+-------+-------+
       |       |       |       |       |       |       |
     leg 0  leg 1  leg 2  leg 3  leg 4  leg 5  ... + IMU + foot sensors
        |
        |  one slave per joint:
        |  yaw drive -> pitch drive -> knee drive
        |
        v
     joint motor (encoder + brake + temp)
```

* **Main loop** runs at 200 Hz on the Jetson. Each iteration:
  1. Read IMU + 6 foot loads + 18 joint angles.
  2. Run state estimation (chassis pose).
  3. Run the gait scheduler (which legs are stance vs swing).
  4. Run inverse kinematics per leg → 18 target angles.
  5. Send target angles + feed-forward torques to the EtherCAT
     drives.

* **Joint drives** close their own current/torque/position loops at
  10 kHz. Drives like Elmo Gold Twitter or the harmonic-drive built-in
  servo packs handle this natively.

* **E-stop** drops the main contactor *and* writes a "freewheel" flag
  to the EtherCAT master so the drives release their brakes only after
  the chassis is detected to be stationary on the ground (otherwise
  it'd collapse on the rider's legs).

### 7.1 Software stack

* ROS 2 Iron / Jazzy
* `ros2_control` for the joint drivers
* `champ` or your own gait scheduler (champ is hexapod-friendly even
  though it's named after a quadruped)
* `robot_state_publisher` consuming a URDF generated from this same
  geometry — see `urdf/hexapod_walker.urdf.xacro` (TODO; not yet in
  this repo)

---

## 8. Assembly sequence

Allow **~ 60 hours of skilled labour for a first build**, half that
for a second. The sequence below is intentionally bolt-by-bolt: every
step gives the fastener ID from §4.2, the count, and the torque. If
you've kitted the per-leg bags in §4.3 you'll always know what comes
next.

> **Before you start:**
> *  Receive every part. Tick off the BOM in §4 line-by-line.
> *  Verify CNC parts with calipers — every motor bore should accept
>    the actual motor with ≤ 0.1 mm gap, every M10 hole should clear
>    a Φ 10.5 mm pin gauge.
> *  Bag fasteners *per joint* using zip-lock pouches labelled
>    "Leg N — yaw / hip-pitch / knee / foot / extrusion". A single
>    leg's hardware fits in 7 bags.
> *  Set up a 1.2 m × 2.0 m flat welding table as the assembly bench.
> *  Read §11 (Safety) end-to-end. Specifically: have a class-C
>    extinguisher within arm's reach during all battery work, and
>    *never* lift a leg sub-assembly without a second person.

### 8.1 Phase 1 — pre-assembly checklist  (~ 4 h)

| Check | Tool | Pass criterion |
|---|---|---|
| Each motor spins freely by hand | bare hands | No grinding, < 0.05 N·m breakaway |
| Each motor's 8 × M8 flange holes accept F1 SHCS | M8 SHCS | Threads start clean, no chip residue |
| Each `coxa_bracket.stl` chassis-pad pattern transfers to the chassis pad with ≤ 0.5 mm error | scribe + calipers | 4 holes line up |
| Each end-cap bore matches its motor flange OD with ≤ 0.1 mm gap | calipers | Slip-fit, no rocking |
| Femur / tibia extrusions cut to 480 / 690 mm ± 1 mm | tape measure | length tolerance |
| Each foot pad has 4 × M10 tapped holes in its embedded steel disc | M10 SHCS | threads start clean |
| EtherCAT cable inventory matches §4.10 (18 motor cables + carriers) | visual | every cable labelled |
| Battery packs charge to 54.6 V each at rest | DMM | matches 16S LiFePO₄ HV |

Sign and date this table on the build log before proceeding.

### 8.2 Phase 2A — chassis fabrication  (~ 8 h, weld + paint)

This subsection assumes you're welding the chassis in-house. If you've
job'd it out (perfectly fine — most local fab shops will quote ~$1,200
from `chassis_hex.stl`), skip to step 12.

1.  Print `chassis_hex.stl` 1 : 1 on a tiled plotter as a layout aid.
2.  Cut **6 × 693 mm** of 80 × 80 × 6 mm sq. tube with **30 ° mitres**
    on each end (perimeter members). 693 mm is the side length of a
    regular hexagon with 1200 mm flat-to-flat — verify with the
    plotter print.
3.  Cut **6 × 380 mm** of the same stock with **square cuts**
    (spokes). 380 mm = apothem (600) − hub radius (180) − 2 × tube
    half-thickness (40), so the spokes butt-weld between the hub OD
    and the perimeter inboard wall.
4.  Cut **1 × Φ 360 mm × 12 mm** disc as the centre hub from
    6061-T6 plate (waterjet or CNC). Drill 4 × M10 × 1.5 tapped
    holes on a **90 mm PCD** (4 holes at 45 ° offsets, 45 mm from
    centre) — these become the saddle-mount bolts F12 later.
5.  Tack-weld the 6 perimeter pieces into a regular hexagon on a flat
    welding deck, flat-to-flat = 1200 mm. Verify with diagonals (any
    two opposite-vertex distances should match within ± 1 mm).
6.  Tack-weld the centre hub disc co-planar with the bottom face of
    the perimeter ring, then tack the 6 spokes from hub OD to each
    perimeter midpoint inboard wall.
7.  CNC-cut (or saw + drill) the **6 chassis edge pads**: **40 × 200
    × 112 mm** 6061-T6 plate, each drilled with 4 × Φ 11 mm clearance
    holes **radially through the 40 mm thickness** in the 160 × 60 mm
    rectangle pattern (160 in Y, 60 in Z; use `chassis_hex.stl` pads
    as the drill template). Each pad sits with its broad face flush
    to the perimeter outboard surface, centred on the perimeter
    midpoint.
8.  Tack-weld each pad to the perimeter tube. **The 4 holes must end
    up exactly aligned with the bracket's chassis-side bolt pattern**
    — clamp the bracket itself onto each pad as a fixture before
    welding.
9.  Inspect for square. Final-weld every joint with full-penetration
    fillet (4 mm leg). Allow to cool naturally — do *not* quench,
    you'll warp the 6063 alloy.
10. Drill **12 × Φ 11.5 mm holes for M8 rivnuts (F10b)** in the
    *top wall of the chassis tube only* — 6 at the perimeter
    midpoints and 6 at the spoke crossings (use `chassis_top_deck.stl`
    as a transfer template; the 12 hole positions are where the deck
    will sit on the tubes). Set one F10b rivnut in each hole with a
    handheld rivnut tool. The rivnut gives F10 (M8 × 25 SHCS) a
    threaded grip without needing access to the inside of the closed
    chassis tube.
11. Etch-prime + powder-coat the chassis (satin black is forgiving of
    weld discolouration). **Mask the rivnut threads and the chassis
    edge pad faces** before painting.
12. **Acceptance:** with the chassis on a flat deck, each chassis pad
    bolt-hole centroid should sit at the same height ± 1.5 mm. If a
    pad is off, shim with a precision washer at install.

### 8.3 Phase 2B — leg sub-assembly  (~ 3 h per leg, ×6 = 18 h)

Repeat this entire subsection **6 times**, once per leg. Each leg
finishes as a free-standing sub-assembly: chassis bracket + yaw motor
+ coxa link + hip-pitch motor + femur + knee motor + tibia + foot,
ready to bolt onto the chassis. Use a sturdy bench; a finished leg
masses ~ 36 kg.

> **How `femur_link.stl` and `tibia_link.stl` map onto the real
> parts.**  Each STL is one continuous solid for visualization, but
> the *physical* leg is **3 separate parts**: a hollow rectangular
> aluminium extrusion (the spar) plus **two CNC-machined end caps**
> (one at each end of the spar). Each end cap consists of:
>
> 1.  **The joint plate** — the 200 mm OD disc you can see at each
>     end of the STL, perpendicular to the joint (Y) axis, with the
>     8 × M8 motor bolt circle and the central output-bore.
> 2.  **A 60 mm boot sleeve** — *not shown in the STL*. Cut from the
>     same 6061-T6 plate stock as the joint plate, this is a
>     rectangular sleeve sized to slide 60 mm onto the end of the
>     extrusion (90 × 120 mm OD for femur, 70 × 90 mm OD for tibia,
>     with a 6 mm wall sleeve so the inside dimension matches the
>     extrusion's outside). The sleeve and joint plate are CNC'd as
>     one piece, or welded into one part before machining.
>
> The 4 × F7 (M10 × 120) through-bolts pass *radially* through the
> sleeve + extrusion + opposite sleeve wall. So **drill 4 × Φ 11 mm
> holes through both walls of the extrusion** in the Y direction
> (femur: through the 90 mm dimension; tibia: through the 70 mm
> dimension), positioned to match the corresponding holes you'll
> drill in the sleeve.

#### 8.3.1 Build the femur extrusion sub-assembly

1.  Lay the femur extrusion (480 mm of 90 × 120 × 6 mm tube) on the
    bench. Slide on the **hip end cap** (a CNC `femur_link.stl`
    half-cap, hip side) over one end.
2.  Mark the 4 × Φ 11 mm through-hole positions from the cap onto
    the extrusion using a scribe; remove the cap; drill through both
    walls of the extrusion on a drill press with a Φ 11 mm bit.
    Deburr inside.
3.  Re-fit the cap. Insert **4 × F7 (M10 × 120)** through the cap +
    extrusion + opposite cap wall, with **2 × F9 washers** under the
    head and the nyloc, and **4 × F8 (M10 nyloc)** on the far side.
    Apply Loctite 271 (red) to threads.
4.  **Torque to 56 N·m** in a star pattern.
5.  Repeat steps 1–4 for the **knee end cap** at the other end of the
    femur extrusion.
6.  Result: assembled femur link, knee plate facing outboard, hip
    plate facing inboard. **Total fasteners used so far on this leg:
    8 × F7 + 8 × F8 + 16 × F9.**

#### 8.3.2 Build the tibia extrusion sub-assembly

7.  Repeat 8.3.1 with the **tibia extrusion** (690 mm of 70 × 90 × 5
    mm tube), the **knee end cap** (`tibia_link.stl` knee side),
    and the **foot end cap** (`tibia_link.stl` foot side).
8.  Same hardware: **8 × F7 + 8 × F8 + 16 × F9**, Loctite 271, 56 N·m.
9.  Result: assembled tibia link with knee and foot plates.

#### 8.3.3 Mount the foot load cell + foot pad to the tibia

The foot pad sandwich, bottom-up, is: **urethane pad → embedded steel
disc (M10-tapped) → load cell sandwich plate → load cell → tibia foot
hub.** The load cell measures the compressive force between the
tibia and the foot pad — this is what tells the controller when each
foot is on the ground.

10. **Foot load cell prep.** Bolt the foot-side of each TAL220 (or
    equivalent) load cell to a small **2 mm × 60 × 30 mm 6061
    sandwich plate** with the 2 × M5 holes the load cell ships with;
    bolt the tibia-side end of the load cell to the **bottom face of
    the tibia foot hub** with another 2 × M5. Centre the load cell
    on the 4 × F6 bolt pattern so the M10 bolts pass on either side
    of it, not through it.
11. With the tibia foot end facing up, place the **foot pad** (cast
    urethane production part) over the load cell sandwich plate so
    the embedded steel disc's 4 tapped M10 holes line up with the
    tibia's Φ 11 mm clearance holes. The load cell + sandwich plate
    sit in the small gap between the foot pad's top face and the
    tibia hub.
12. Insert **4 × F6 (M10 × 50)** down through the tibia hub, past
    the load cell on either side, into the steel disc's tapped
    holes. Loctite 243.
13. **Torque to 56 N·m** in a cross pattern. The load cell is now
    pre-loaded by the M10 bolts — its zero offset will be captured
    in §8.9 commissioning.
14. Route the load cell's 4-conductor cable up through the tibia's
    PG-9 cable gland (entering the tibia hub side wall) and leave
    the bay-side end coiled at the knee for now — wired up properly
    in §8.7 step 4.

#### 8.3.4 Mount the knee motor (motor #2 of this leg)

> **Bolt-direction convention used in §8.3.4–§8.3.6:** every F1 SHCS
> always passes **through the link plate** (which has Φ 9 mm
> *clearance* holes) and **threads into the motor flange** (which
> has tapped M8 holes). So the head of every F1 sits against the
> link plate, the threads bite the motor flange. With the link
> plate-down and the motor sitting on top of it, you drive each F1
> from *underneath* the bench (lay the link on edge or use a hole in
> the bench top). With the motor-down and the link on top of it,
> drive each F1 from above. Either is correct as long as **the head
> is always on the link side**.

15. Place the femur link knee-plate-up on the bench, knee plate
    horizontal. Set the **knee motor** body-down onto the plate so
    the **motor body's mounting flange** mates flat to the knee
    plate, and the motor's 8 tapped M8 holes align with the plate's
    8 Φ 9 mm clearance bolt circle.
16. Insert **8 × F1 (M8 × 30 SHCS)** through the plate **upward into
    the motor body flange.** A drop of Loctite 243 on each thread.
    **One F2 (split-lock) under every head.**
17. **Torque to 28 N·m in a star pattern (1, 5, 3, 7, 2, 6, 4, 8) in
    three passes (30 / 70 / 100 %).**
18. Cradle the femur in a soft-jaw vice. Pick up the tibia
    sub-assembly and align its knee plate against the knee motor's
    output flange (now sticking up from the femur). The output
    flange's 8 tapped holes line up with the tibia knee plate's 8
    Φ 9 mm clearance bolt circle.
19. Insert **8 × F1 + 8 × F2** down through the tibia plate **into
    the motor output flange.** Loctite 243.
20. **Torque to 28 N·m in star pattern.**
21. Verify the knee rotates freely through its full ± 70 ° range
    when you back-drive it by hand (motor power off, brake released
    by tapping the brake-release pin to GND with the 24 V house
    battery if your motor needs it). **No binding.**

#### 8.3.5 Mount the hip-pitch motor (motor #1 of this leg)

22. Build the coxa link sub-assembly first. Set `coxa_link.stl`
    (CNC 6061-T6 part) on the bench, pitch plate horizontal,
    pitch-plate face up.
23. Set the **hip-pitch motor** body-down on the pitch plate. **8 ×
    F1 + 8 × F2**, Loctite 243, **28 N·m star pattern.** The
    motor's output flange now sticks up from the coxa link.
24. Pick up the femur sub-assembly (which now carries the knee motor
    + tibia + foot — about 22 kg). With a helper, lower it so the
    femur's hip plate sits flat on top of the hip-pitch motor's
    output flange. The femur's spar extends sideways from the coxa
    link, parallel to the bench.
25. Insert **8 × F1 + 8 × F2** down through the femur hip plate
    **into the motor output flange.** Loctite 243.
26. **Torque to 28 N·m in star pattern.**
27. Back-drive the hip-pitch joint by hand through ± 60 °. No
    binding.

#### 8.3.6 Mount the yaw motor and coxa bracket

> **Motor orientation assumption:** the standard FHA-40C-100 has its
> mounting flange on the **rear** (motor body) face, and its rotating
> output protrudes from the **front** face. Step 28 below puts the
> rear flange on the *bottom* plate of the bracket cradle, with the
> output protruding *upward* through the cradle's top bore. If your
> motor instead has the flange on the front (output side) — common
> for ODrive / MyActuator — flip the orientation: motor flange on
> the *top* plate of the cradle, body hanging *down* into the
> cradle. The 8-bolt circle is the same either way.

28. Set the **coxa bracket** (`coxa_bracket.stl`) bottom-plate-up on
    the bench. Drop the **yaw motor** rear-flange-down into the
    cradle so its 8-hole flange aligns with the bottom plate's 8
    Φ 9 mm clearance bolt circle, and its output rotor points *up*
    through the bracket's top bore.
29. Insert **8 × F1 + 8 × F2** up through the bracket bottom plate
    **into the motor rear flange.** Loctite 243.
30. **Torque to 28 N·m in star pattern.**
31. Pick up the coxa link + femur + everything below sub-assembly
    (~ 30 kg — get a helper or a small hoist). Present the coxa
    link's bottom hub against the yaw motor's output flange on top
    of the bracket. The hub's 8 Φ 9 mm clearance bolt circle aligns
    with the output flange's 8 tapped holes.
32. Insert **8 × F1 + 8 × F2** down through the coxa hub **into the
    output flange.** Loctite 243.
33. **Torque to 28 N·m in star pattern.**
34. Back-drive the yaw joint by hand through ± 45 °. No binding.

#### 8.3.7 Per-leg fastener tally

You should have used, per leg:

* **48 × F1 (M8 × 30)** + **48 × F2 (lock washer)** — motor mounts
* **16 × F7 (M10 × 120)** + **16 × F8 (nyloc)** + **32 × F9 (washer)**
  — extrusion through-bolts
* **4 × F6 (M10 × 50)** — foot pad

If your bag is empty and you have no leftovers, you're done. If you
have leftovers — stop and figure out which joint is missing fasteners
*before* the leg goes on the chassis.

#### 8.3.8 Pre-flight bench check (before installing on chassis)

35. With the leg lying horizontal on the bench, manually flex each of
    the 3 joints through its full range. Listen for any tick or grind.
36. Mark each joint's "zero" position with a paint pen so you can
    verify encoder zero during commissioning.
37. Tag the leg with its leg number (0–5) and which side it goes on.

### 8.4 Phase 2C — battery pack sub-assembly  (~ 4 h, electrician
required)

> Battery work below 60 V DC is generally OK for a non-electrician;
> the inter-pack series link in this section creates a 96 V DC bus
> that **can kill you on contact**. Have an electrician present.

1.  Assemble the **battery box** body per `battery_box.stl`
    (TIG-welded 4 mm 5052 sheet, or order as a sheet-metal job).
2.  Mount **2 × 48 V × 50 Ah LiFePO₄ packs** inside, separated by 5
    mm closed-cell EPDM foam.
3.  Strap each pack down with one of the **2 × ratchet straps**.
4.  Wire the **inter-pack series link** (one 4 AWG M8-ringed cable
    with the **100 A class-T fuse** in line). Torque the M8 stud
    nuts to **15 N·m**.
5.  Verify with a meter: **bus voltage at rest = 96 ± 2 V DC.**
6.  Bring a **2 AWG positive lead** to the **main contactor's load
    side**, and a matching negative lead to the bus negative.
    **Do not connect the contactor to the bus yet.**
7.  Wire the **pre-charge resistor + relay** in parallel with the
    main contactor.
8.  Wire the **bus-bleed LED + 100 kΩ resistor** between bus + and
    bus – inside the box. This LED tells you whether the
    high-voltage bus is live.
9.  Bolt the **8 mm 6061 lid** down with **12 × F15 (M5 × 16)**,
    **5 N·m each.** Apply silicone sealant on the gasket.

### 8.5 Phase 2D — electronics bay sub-assembly  (~ 4 h)

> **Where do the 18 motor drivers actually live?**  The
> `electronics_bay.stl` (360 × 240 × 140 mm internal) is sized for
> the **controller + power-distribution** stack, *not* for 18
> standalone drivers. There are two architectures depending on which
> motor you bought (§4.1):
>
> *  **FHA-40C-100 with built-in drives (recommended).**  Each motor
>    has its own EtherCAT-slave drive integrated in the housing.
>    The bay holds *only* the controller + IMU + DC-DC + EtherCAT
>    master + power-distribution PCB. **No driver row inside.**
>
> *  **ODrive / external-driver route.**  Each ODrive Pro is ~120 ×
>    65 × 30 mm and won't fit 18-up in the bay. Mount the 18 drivers
>    in **a separate driver enclosure** (e.g. 600 × 400 × 200 mm
>    sealed steel cabinet from any electrical wholesaler, ~$150) and
>    bolt that to the top deck **in the rear position alongside the
>    battery box**, with its own 4 × F10 + 4 × F10b mount pattern.
>    The bay then only carries the controller + IMU + ECat master.
>
> The remaining steps assume the FHA-with-built-in-drive route. For
> the ODrive route, replace step 2 with "wire each ODrive's
> EtherCAT-or-CAN port + power leads through the driver enclosure's
> own glands" and skip step 5.

1.  Assemble the **electronics bay** body per `electronics_bay.stl`.
    Fit **7 × PG-13.5 cable glands** to the punched holes.
2.  DIN-rail mount the **EtherCAT master**, the **24 V → 12 V
    DC-DC**, the **24 V house battery terminal block**, and the
    **96 V → 24 V isolated DC-DC** inside the bay.
3.  Mount the **main controller (Jetson / IPC)** on M3 standoffs at
    the rear of the bay (4 × F17 self-tappers).
4.  Mount the **9-DOF IMU** on a foam-isolated standoff at the bay
    centre, IMU axes aligned with the chassis frame (verify in
    §8.8).
5.  Run the EtherCAT trunk cable from the master out through one of
    the cable glands. The 18 motor jumpers will daisy-chain to it
    in §8.7.
6.  Mount the **6 × HX711 load-cell amplifier boards** in a row
    along one wall, with their 4-pin terminals facing the bottom
    glands.
7.  Bolt the **3 mm sheet-metal lid** down with **8 × F15 (M5 × 16),
    5 N·m each.** Apply silicone sealant on the gasket.

### 8.6 Phase 3 — final mechanical mating  (~ 6 h, 2-person)

1.  Place the **bare chassis** on 4 saw-horses, **chassis spokes
    radiating outward from the centre hub, edge pads pointing
    outboard, top face (the side with the 12 F10b rivnuts) facing
    up**. The saw-horses should support the chassis with all 6
    edge pads at least 700 mm above the floor — this gives the legs
    room to hang once they're mounted.
2.  Pick up **leg 0** (your first sub-assembly from §8.3). With a
    helper or a small chain hoist, present the coxa bracket's
    chassis-side flange against the chassis pad in the leg-0
    position. The bracket's 4 Φ 11 mm holes line up with the pad's
    4 Φ 11 mm holes.
3.  Insert **4 × F3 (M10 × 90)** through bracket + pad. **Each F3
    gets: 1 washer F5 under the head, 1 washer F5 under the F4
    nyloc nut.** Loctite 243 on threads.
4.  **Torque to 56 N·m in cross pattern.**
5.  Repeat for legs 1, 2, 3, 4, 5. Each chassis pad is identical, so
    the legs are interchangeable. **Total: 24 × F3, 24 × F4, 48 ×
    F5.** Walking time: ~ 4 h with one helper.
6.  Stand back. The walker now hangs from the saw-horses with all
    6 legs dangling.
7.  Drill the top deck. Lower the **top deck**
    (`chassis_top_deck.stl`, 12 mm 6061 plate) onto the chassis.
    Mark each of the **12 chassis-tube rivnut centres** through the
    deck with a transfer punch, then lift the deck off and drill
    **12 × Φ 9 mm clearance holes** at the punch marks.
8.  Re-lower the deck. Insert **12 × F10 (M8 × 25 A2-70)** down
    through the deck **into the F10b rivnuts** in the chassis tube
    top wall. Loctite 243. **Torque to 18 N·m.**
9.  Install the **saddle mount** (`saddle_mount.stl`) by lowering
    its base over the centre hub disc's 4 tapped M10 holes (90 mm
    PCD). Insert **4 × F12 (M10 × 25 A2-70)** through the base into
    the hub. Loctite 243. **Torque to 56 N·m.**
10. Install the **suspension seatpost + saddle** in the saddle
    mount's collar.
11. Install the **2 × footrest studs** (F18) by welding them to the
    +X edge of the top deck (rider's foot stations), per the rider
    geometry. Bolt the **rider footpegs** onto the studs.
12. Install the **harness mounting points**: 2 × F14 (M6 × 20) at
    the saddle's rear corners, 2 × F14 over the rider's shoulders
    on a tubular crossbar welded to the seatpost top.
13. Place the **battery box sub-assembly** from §8.4 onto the top
    deck in the rear position. Mark its 4 mounting holes through
    the deck with a transfer punch. Lift the box, drill **4 × Φ 11.5
    mm holes**, and set **4 × F10b rivnuts** at those positions.
    Re-set the box, then bolt **4 × F10 (M8 × 25) into the F10b
    rivnuts.** Loctite 243. **Torque to 18 N·m.**
14. Place the **electronics bay sub-assembly** from §8.5 onto the
    top deck in the front position. Same procedure: punch, drill,
    set 4 × F10b rivnuts, bolt with **4 × F10**, **18 N·m.**

### 8.7 Phase 4 — power and signal wiring  (~ 6 h, electrician required)

> All steps in this section assume the **main contactor is open and
> the E-stop is pressed** — i.e. the 96 V bus is dead at the
> drivers. **Verify with a meter before touching any motor lead.**

> **Cable routing convention.** All trunk cables run **between the
> top deck and the top face of the chassis tubes** — i.e. they hug
> the underside of the deck, fanning out from the electronics bay
> straight to each leg's chassis edge pad. The 12 mm gap created by
> the rivnut shoulder washers + sealing gaskets is enough for the
> bundle. **Do not** try to route cables through the welded chassis
> tubes — they're sealed.
>
> At each chassis edge pad, every cable destined for that leg drops
> down through a **single PG-13.5 cable gland in the side wall of
> the coxa bracket** and into the leg-side cable carrier system
> (3 carriers per leg: yaw, hip-pitch, knee).

#### 8.7.1 Mount cable carriers on each leg  (do this first)

1.  At each of the 18 joints, mount one **igus E-chain carrier
    (250 mm long, 30 × 50 mm cross-section)** with **2 × F13 (M6 ×
    16)** at each carrier end mount-plate (one mount-plate to the
    static side, one to the rotating side). 18 carriers × 2 ends ×
    2 F13 = **72 F13** for the carrier mounts. Per-leg: 6 F13 across
    3 carriers.
2.  For the **yaw carrier**: static mount on the coxa bracket's
    outboard wall; moving mount on the coxa link's bottom hub
    rim. Pre-arc so the carrier curls *downward* through ±45 ° of
    yaw motion.
3.  For the **hip-pitch carrier**: static mount on the coxa link's
    pitch plate; moving mount on the femur's hip-end cap rim.
4.  For the **knee carrier**: static mount on the femur's knee-end
    cap rim; moving mount on the tibia's knee-end cap rim.

#### 8.7.2 Route motor power and load cell cables

5.  Route the **6 × yaw motor power cables (1.2 m each, F4
    cable from §4.10)** from the electronics bay along the
    deck-underside trunk, out to each chassis edge pad's gland,
    and into the **bottom-plate side-wall connector of the coxa
    bracket** (yaw motor sits inside the bracket — the cable
    enters via a PG-9 gland in the bracket's side wall and lands
    on the FHA-40C's connector). Termination (driver side):
    4 × ferrule per cable into the driver power terminals.
6.  Route the **6 × hip-pitch motor power cables (1.8 m each)** the
    same way, but pass each through the **yaw cable carrier**
    before plugging into the hip-pitch motor. The carrier protects
    the cable as the yaw joint rotates.
7.  Route the **6 × knee motor power cables (2.5 m each)** through
    **two carriers per cable** (yaw → hip-pitch) before terminating
    at the knee motor (which is mounted on the femur — does not
    move with the knee joint, so the knee carrier itself is *not*
    needed for the knee motor's power cable).
8.  Wire the **6 × foot load cell cables** through the **PG-9
    glands at the bottom of each tibia foot hub** (already coiled
    there from §8.3.3, step 14). Each load cell cable runs up
    through *all three* carriers (knee → hip-pitch → yaw) and into
    one of the bay's HX711 board terminals. Use spiral cable wrap on
    the long sections.

#### 8.7.3 Route signal cables

9.  Route the **18 × M12 X-coded EtherCAT jumpers** alongside the
    power cables (separated by ≥ 25 mm or with a grounded shield).
    **Daisy-chain order (chain, not ring):** ECat master → leg 0
    yaw → leg 0 hip → leg 0 knee → leg 1 yaw → ... → leg 5 knee →
    *terminator plug*. **Cable count: 18** for the chain. *(Optional
    upgrade: add a 19th cable from leg 5 knee back to the master to
    close into a redundant ring — buy one extra M12 jumper if you
    want this.)*
10. Route the **18 × 24 V brake-release lines** (one per joint),
    sharing the EtherCAT bundle. Land at each drive's 24 V
    brake-out terminal.
11. Wire the **handlebar E-stop (1 ×)** from the saddle area to the
    contactor coil. The E-stop is in series with the **key switch**
    on the saddle mount; both must be closed for the contactor to
    pull in.

#### 8.7.4 Final cable check

12. **Visual sanity check:** with the legs in mid-flex, gently sweep
    each joint through its motion range. **No cable should pull
    tight or pinch in any joint position.** If one does, add slack
    at the bay end. Re-verify after every joint extreme.

### 8.8 Phase 5 — first power-up (logic only)  (~ 2 h)

1.  **Confirm:** main contactor open, E-stop pressed, key switch
    off, bus-bleed LED off (no high voltage), main battery
    disconnect open, walker on saw-horses with feet clear of the
    floor.
2.  Connect the **24 V house battery** to the electronics bay.
3.  Power up the IPC / Jetson. Watch boot logs.
4.  In a terminal: `ros2 launch hexapod_walker bringup.launch.py`.
5.  **Acceptance:** all 18 EtherCAT slaves enumerate, each reports
    a sane encoder position, no error flags.
6.  Fire the IMU. Check `ros2 topic echo /imu/data` — gravity
    vector should point through the chassis +Z axis when the
    walker sits flat on the bench. If not, your IMU mounting is
    rotated; fix in the URDF transforms.
7.  Power down. Confirm log file written for first-power-up event.

### 8.9 Phase 6 — joint commissioning (one joint at a time)
(~ 4 h)

> **Critical safety:** for each joint, a helper holds the link
> against possible runaway rotation while you energise. Both wear
> safety glasses. The legs are still hanging in the air; if a motor
> commands a hard slew, the leg whips around and can break a wrist.

1.  Close the main battery disconnect and the contactor key switch.
    Press E-stop release.
2.  Issue **brake-release** on **only the leg 0 yaw drive**. Manually
    confirm that the leg now swings freely about the yaw axis.
3.  Issue a **slow position command (5 °/s, ± 5 °)** to leg 0 yaw.
    Watch direction of rotation — must match the URDF's positive
    yaw convention. If reversed, flip the motor's `inverted` flag
    in the driver config.
4.  Repeat for leg 0 hip-pitch, then leg 0 knee. Then move to leg 1,
    and so on, all 18 joints.
5.  For each joint, write down the **encoder zero offset** (the
    encoder count when the joint sits at the paint-pen mark from
    §8.3.8). Save these to the URDF.
6.  Re-press E-stop. Verify all 18 brakes engage within 100 ms.

### 8.10 Phase 7 — slow-stand bring-up  (~ 1 h)

1.  Walker still on saw-horses, all 6 feet ~ 200 mm above the
    floor. Confirm safety perimeter (no tools, hands, cables under
    the feet).
2.  Run `ros2 service call /walker/slow_stand
    std_srvs/srv/Trigger`. The controller commands all 6 feet
    downward at 0.02 m/s in unison.
3.  When all 6 feet contact the floor (foot load cells > 50 N), the
    controller transitions to **"floor-contact stand"** and slowly
    transfers chassis weight from the saw-horses to the legs.
4.  After ~ 30 s, all foot load cells should read **~ 460 N each**
    (the 280 kg chassis evenly distributed across 6 feet).
5.  **Lift the saw-horses out from under the chassis.** The walker
    is now free-standing on its own legs.
6.  Verify the chassis stays level (IMU pitch + roll within ± 1 °)
    for at least 5 minutes with the standing controller engaged.

### 8.11 Phase 8 — first walk (no rider)  (~ 2 h)

1.  Clear a 5 m × 5 m flat, clean, level area around the walker.
2.  Issue `/walker/walk_slow` (0.05 m/s, wave gait — only 1 leg in
    swing at a time, 5 planted). The walker should advance ~ 0.05
    m/s for 1 minute, then halt.
3.  Listen for any binding, ticking, or motor whine. Watch for
    cable pinching at any joint extreme.
4.  Inspect every joint's bolts for any sign of loosening (paint-pen
    a witness mark across each F1 head + plate before the walk;
    if the mark is broken after, that bolt has rotated).
5.  Repeat at 0.1 m/s, then 0.2 m/s, then full cruise (0.4 m/s).
6.  Run for 30 minutes total. **Re-torque every accessible F1 to
    28 N·m, every F3 to 56 N·m** after the first run.
7.  Charge battery. Re-test next day.

### 8.12 Phase 9 — first ride  (~ 1 h, 2 spotters required)

> A 280 kg machine moving 0.4 m/s with a 110 kg human aboard has
> serious kinetic energy. The first ride is on **flat indoor
> concrete** with a 4-point harness and a helmet, surrounded by 4
> spotters with foam barriers, at quarter-speed (0.1 m/s).

1.  Rider mounts the saddle and clips into the harness. Spotters in
    position. E-stop within rider's reach.
2.  Issue `/walker/walk_slow` at 0.1 m/s. Walker carries rider 5 m
    forward, halts.
3.  Repeat at 0.2 m/s, then 0.4 m/s. Each test, listen for any
    change in motor sound or chassis behaviour.
4.  After 30 min of cumulative ride time, **re-torque every F1
    (28 N·m) and F3 (56 N·m).**
5.  You're done. The walker is commissioned.

### 8.13 Maintenance schedule

| Interval | Task |
|---|---|
| Every 1 h ride time | Visual: any cable pinch, any leaking grease, any unusual noise |
| Every 8 h ride time | Re-torque every F3 (56 N·m), every F6 (56 N·m), every F1 visible without disassembly (28 N·m) |
| Every 40 h ride time | Full F1 torque pass on all 18 motors (requires partial disassembly), check encoder zeros, re-grease cable carriers |
| Every 100 h | Inspect femur / tibia extrusions for any visible deformation or paint cracking near the end caps; if cracking, replace extrusion |
| Every battery cycle | Log capacity. Replace pack at 80 % capacity loss (≈ 800 cycles for LiFePO₄) |
| After any fall | Full 18-motor torque pass. Inspect every link with dye penetrant or visual for cracks. Replace any visibly bent extrusion. |

---

## 9. Gait

The default gait is a classic **alternating tripod**:

```
                 leg 0     <- right-front
        leg 5  ---X---  leg 1
              /       \
   leg 4 --- chassis --- leg 2
              \       /
        leg 3  ---X---
                 (no leg here -- legs are at edges, not vertices)
```

Legs `{0, 2, 4}` form one tripod, `{1, 3, 5}` form the other. Each
half-cycle:

1. Tripod A's three feet are planted ("stance"). They push the chassis
   forward by sweeping their hip-yaw joints rearward. Femur and knee
   joints maintain a constant chassis height.
2. Simultaneously, tripod B's three feet are in the air ("swing").
   They lift, swing forward to the next foothold, and re-plant.
3. The roles swap.

At cruise the cycle takes ~ 1.5 s per stride; with a 0.6 m stride that
gives 0.4 m/s ground speed.

For climbing or stepping over obstacles the controller falls back to a
**wave gait**: one leg in swing at a time, the other five planted —
slower (~ 0.1 m/s) but maximally stable.

---

## 10. Cost summary

| Bucket | Low | High |
|---|---|---|
| 18 × actuators (FHA-40C-100 retail vs. used / DIY cycloidal) | $25,000 | $130,000 |
| Structural (extrusion + tube + plate) | $1,500 | $3,500 |
| CNC / cast end caps & brackets | $4,000 | $9,000 |
| 3D-printed parts (HP MJF or local SLS) | $1,500 | $4,000 |
| Battery system (packs + contactor + pre-charge + fuses + E-stop, §4.8) | $1,400 | $2,800 |
| Motor drivers (18 ×) | $5,000 | $30,000 |
| Compute + IMU + foot sensors (§4.9) | $1,800 | $5,200 |
| Wiring harness (cables + glands + lugs + carriers, §4.10) | $1,000 | $2,500 |
| Saddle, harness, footpegs (§4.11) | $400 | $1,200 |
| Fasteners (every line in §4.2 + §4.3) | $300 | $700 |
| Tools you don't already own (§4.12, mostly the torque wrench + crane hire) | $300 | $1,500 |
| Consumables (Loctite, paint, anti-seize, cable ties, §4.13) | $200 | $500 |
| **Total** | **~ $42,400** | **~ $190,900** |

Realistic mid-range: **$60 – $80 k** if you go DIY on the actuators
(BLDC + custom cycloidal) and use Xometry / PCBWay for the structural
parts.

---

## 11. Safety

This vehicle can crush, pinch, electrocute, and fall. Read this list
and *do not skip any of it*.

* **Eighteen motors with 1.5 kN·m peak torque can amputate fingers.**
  Never reach into a moving leg. Park the walker on saw-horses with
  the legs unloaded before any maintenance. Fit the motor brakes *on*
  before unbolting any link.
* **96 V DC is enough to kill.** Treat the battery loop as live unless
  the contactor is open *and* the bus capacitors are bled (LED on the
  electronics bay). Never service the battery without an electrician
  present.
* **The walker is statically stable in tripod stance, but only if at
  least three properly-spaced feet are on the ground.** Power loss
  during a swing-phase = the chassis drops 200 mm onto whatever leg
  was about to plant. Software must sequence E-stop → gait freeze
  → land all 6 → de-energise. The supplied controller pseudocode
  (§7) does this.
* **Falls on uneven ground are when riders get hurt.** Wear a 4-point
  harness and a helmet. Don't ride above 0.2 m/s on slopes > 15 °.
* **Pinch points** at every hub (where the link rotates past the
  motor body). Bright-yellow pinch-point decals on the
  outboard face of every coxa, femur, and tibia hub.
* **Thermal:** an FHA-40C running near continuous torque draws 800 W
  and dissipates ~ 100 W as heat. After a 30-minute walk the motor
  housings are at ~ 70 ° C — hot enough to burn skin. Don't grab a
  motor housing post-walk.
* **Legal:** in most jurisdictions a 280 kg unregistered electric
  vehicle is **not** street-legal. Build it for private property.
  Check local UAV/robot regulations; some states class anything
  > 25 kg with autonomous control as a robotic vehicle subject to
  registration.

---

## 12. Hot-rodding ideas

Once the basic walker is running, here's where to take it:

* **Hydraulic upgrade:** swap the rotary servos for double-acting
  hydraulic cylinders on parallelogram links. Pump driven by a
  Kubota 3-cyl diesel on the top deck. Now you have a Stompy.
* **Pose-shifting platform:** add a 6 × 6 Stewart-platform top deck
  so the rider's saddle stays level when the chassis pitches over
  uneven ground.
* **Quadrupedal mode:** lift the front two legs off the ground and
  use them as manipulators. The arms have plenty of reach (1.5 m).
* **Cargo variant:** strip the saddle, add a 600 mm flatbed top
  deck, carry up to 250 kg of cargo over rough ground.
* **Outdoor autonomy:** add a Velodyne or Livox LiDAR on a
  3 m mast for dynamic foothold planning.

---

## 13. References

* **Open-source big walkers:**
  - [Project Hexapod / Stompy](https://www.projecthexapod.com/) — the only successful >100 kg-payload hexapod with public docs.
  - [Mantis hexapod](https://www.youtube.com/watch?v=OrsMdsLG7DU) by Matt Denton — engineering reference.
* **Servomotors:**
  - Harmonic Drive [FHA-C series datasheet](https://www.harmonicdrive.net/products/actuators/fha-c-mini-series).
  - MyActuator [RMD-X12 series](https://www.myactuator.com/rmd-x12-series).
* **Software:**
  - [`ros2_control`](https://control.ros.org/), [`champ`](https://github.com/chvmp/champ) hexapod gait library.
  - James Bruton's [openDog / hexapod tutorials](https://github.com/XRobots) — invaluable for the DIY actuator route.

---

## 14. Disclaimer

This design is provided as a starting point for hobbyist builders who
have professional engineering review available. **The author has not
built and tested this exact walker.** All numbers in §5 and §10 are
rough hand-calcs with single-digit-percent tolerance; a real build
needs a proper FEA pass on the femur and tibia, fatigue analysis on
all six hip-yaw weld joints, and a thermal-management plan for the
motor stack. Build at your own risk.

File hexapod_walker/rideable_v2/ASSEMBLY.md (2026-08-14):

# `rideable_v2` — Assembly Order (draft)

> Build order for the stand-in design; the BuildViz scene
> (`full_robot_viz/scene.json`, regenerate with `make viz`) shows every
> part named below in its home (parked) pose. Belt runs are not modelled
> in the scene — each stage's driver, driven pulley, and center distance
> are in [`PARTS.md` §2](PARTS.md#2-belt-drives-18-stages).

## 1. Single-joint bench rig first

Per [`BOM.md` §L](BOM.md#l-bench-test-order-de-risk-before-buying-18):
one hip joint (actuator → 8MGT-960-36 belt → 30205 shaft → lever arm),
its parking-pin lock, and a load to 0.36 kN·m — before ordering the
fleet.

## 2. Leg assembly (×6, identical)

1. **Coxa**: machine the yaw hub + box link + hip clevis as one weldment
   (`coxa_frame`). Press the yaw 32006 bearing pair; bolt the 72T yaw
   pulley (`yaw_pulley`) to the hub top.
2. **Hip joint**: press 30205 pairs into the coxa clevis **back-to-back**
   (O-arrangement — the single-shear moment needs the wide effective
   spread, [`PARTS.md` §3](PARTS.md#3-structural-joint-bearings-18-sets));
   fit the Ø25
   joint shaft (`hip_pivot_pin`) through the femur hub; bolt the 100T
   pulley (`hip_pulley`) — with its parking-pin hole ring — to the femur
   hub face. Mount the hip AK80-64 (`hip_actuator`) on the coxa face
   plate at C = 208 mm with the 25T sprocket hub through its **6905-2RS
   pilot bearing** ([`PARTS.md` §2](PARTS.md#2-belt-drives-18-stages)).
3. **Hip lock, then belt** (order matters): bench-verify the pin-lock
   clevis (`hip_lock`) spring-engage / solenoid-retract, then set it
   aside — the endless belt slides over the pulley **axially**, and a
   mounted lock body blocks that pass. Slip belt 8MGT-960-36 over the
   pulleys, THEN bolt the lock clevis to the coxa so the pin lines up
   with the web holes at r = 90 mm, fit the eccentric idler, and
   tension per [`PARTS.md` §2](PARTS.md#2-belt-drives-18-stages).
4. **Femur + knee drive**: the knee AK80-64 (`knee_actuator`) mounts
   ~140 mm from the hip axis on the femur's opposite face (with its own
   pilot bearing); its 3:1 belt (8MGT-896-36, C = 212 mm) runs down the
   femur to the 84T knee pulley (`knee_pulley`) bolted to the tibia
   hub. Knee joint shaft + 30205 pair as at the hip; knee lock
   (`knee_lock`) on the femur — same belt-before-lock order.
5. **Tibia + foot**: Ø50 tube (`tibia_frame`) to the ankle boss; foot
   pad + load cell (`foot`).
6. Fit belt guards and the mechanical travel stops
   ([`STRUCTURE.md` §5](STRUCTURE.md#5-mechanical-travel-stops)).

## 3. Chassis & body

1. Weld the hex frame (`chassis_frame`), fit the six vertex plates.
2. Hang the six yaw actuators (`yaw_actuator`) under the plates
   (C = 136 mm inboard of each yaw axis); fit yaw belts 8MGT-720-36.
3. Bolt each leg's yaw shaft (`yaw_pivot_pin`) up through the vertex
   plate.
4. Deck (`deck_plate`), battery (`battery`, low + central), e-bay
   (`e_bay`), saddle post + saddle, handlebar with e-stop (`controls`),
   footpegs.

## 4. Electrical & commissioning

Wire per [`POWER_SYSTEM.md`](POWER_SYSTEM.md) §1/§4 (pack → Class-T →
pre-charge + contactor → six 30 A branches; 24 V rail → 12 lock
solenoids through default-open drivers). Commission per
[`POWER_SYSTEM.md` §6](POWER_SYSTEM.md#6-hazards--commissioning) and the
ballast stages in [`README.md` §9](README.md#9-safety--ballast-protocol)
— **no rider until ballast testing passes.**

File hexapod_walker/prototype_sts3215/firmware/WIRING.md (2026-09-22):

# Hexapod prototype — wiring & bench bring-up (FEETECH bus servos)

Buildable wiring plan for the **18× FEETECH STS3215** serial-bus
hexapod, plus a bench bring-up checklist so you test everything **on a
current-limited bench supply first**, before the LiPo is ever
connected. Pair this with the host-side driver in
`../motor_setup/feetech_bus.py`.

> **Rendered harness diagram:** the full connector-by-connector WireViz
> diagram (with wire colors, gauges and the auto-generated BOM) lives at
> [`harness.svg`](harness.svg) / `harness.png` / `harness.html` next to
> this file. Regenerate it (after editing this doc's topology or the
> geometry in `../motor_setup/wire_harness_plan.py`) with
> `../scripts/render_harness_diagram.py` (repo venv).

**June 2026 redesign.** The prototype uses **18× FEETECH STS3215**
(ST-3215-C018, 12 V / 30 kg·cm) **serial-bus** smart servos (6 legs ×
yaw/hip/knee). Each servo has a built-in 12-bit magnetic encoder and
reports **position, load, voltage, current and temperature** back over
the bus, so the robot has closed-loop joint feedback with **no external
sensors**. This deletes most of the old stack: **no Arduino Mega, no
PCA9685 PWM boards, no servo BECs, and no AS5600 encoders.**

The controller is an **Arduino Uno Q** (on-board Linux SoC + MCU).
Python gait / teleop / demos run on the **Linux** side.

**Preferred bus path (live):** the STM32 MCU sketch
[`feetech_bridge`](feetech_bridge/) owns **D0/D1 → FE-URT UART at 1 Mbps**.
Linux talks to the sketch over **`/dev/ttyHS1` @ 921600** (2 Mbaud was tried 2026-09-22 and
corrupted host->MCU bytes; see HOST_BAUD in the sketch).
Since 2026-09-22 (`HELLO ... proto=2`) the control tick is the compact `'V'`/`'T'` pair (41 bytes out,
100 back) instead of `'S'` (113 + 134); the host falls back to `'S'` on an older sketch.
(`linux_control/mcu_feetech_bus.py`).

**Power (Aug 2026 as-built):** **no external buck, no PDB**. The 3S
battery feeds two domains that share ground only — `battery → trunk
Wagos → power Wagos → servos` (the whole distribution is Wago 221 lever
nuts) and `battery → Uno Q` (on-board regulator). Electronics deck =
magnet-held round Ø115 mount plate (Uno Q + breakout on top, 3.3 V Wago
underneath) + raised platform (screen
on top; MPU glued on chassis_top beside the central trunk Wagos).

**Fallback (bench only):** a **USB bus-servo adapter** (FE-URT-2 or
Waveshare) on the Uno Q USB-C OTG port, enumerated as `/dev/ttyUSB*`,
driven directly by `feetech_bus.py` at 1 Mbps — useful when the MCU
bridge is not flashed.

> ⚠ **The USB fallback does NOT work when the Uno Q is VIN-powered**
> (i.e. on-robot, battery → VIN).  Two documented Uno Q issues: with no
> USB-C cable at boot there is no CC negotiation, so the USB controller
> comes up in **device** mode (fixed in newer OS images; older ones need
> `echo host | sudo tee /sys/kernel/debug/usb/4e00000.usb/mode`, see
> [arduino/linux-qcom#2](https://github.com/arduino/linux-qcom/issues/2));
> and the board **never sources 5 V out of the USB-C jack from VIN** (a
> diode isolates VBUS from 5V_SYS), so the adapter stays unpowered
> unless it hangs off a powered PD hub.  This is why the robot uses the
> **D0/D1 UART path** — it is the only practical link under VIN power.

> **Buy one USB/TTL bus-servo adapter** (needed for either UART or USB mode):
> - **FEETECH FE-URT-2** (`FE-URT2-C001`) — Type-C, TTL-BUS for STS/SCS,
>   RS485 for SMS, **3.3 V / 5 V** logic switch (set **5 V** for USB host
>   mode; MCU UART path is 3.3 V-safe via the Uno Q pins — follow the
>   bridge wiring).  Screw terminal for servo power.
> - **Waveshare Bus Servo Adapter (A)** (SKU **25514**) — USB-C, D/V/G
>   header; jumper **A = UART to MCU**, **B = USB to host**.
>
> **USB-C host note:** when using the USB fallback, the Uno Q's single
> Type-C is in **OTG / host** mode — use a hub with power passthrough if
> you still need to power/debug the board over USB.

> **Laptop → adapter USB-C (bench):** you can also drive the bus
> straight from a laptop plugged into the on-deck Waveshare adapter's
> own USB-C (jumper **B**), bypassing the Uno Q entirely.  The CAD
> guarantees this is physically possible without unstacking anything:
> the adapter's -X (terminal/USB) face keeps a **30 mm bench-plug
> corridor** of free air (`MOTOR_CTRL_USB_CLEAR`, enforced by the viz
> `connector_clearance` check).  The corridor extends past the deck rim
> into leg airspace, so it is **parked-robot only** — limp the servos
> before tethering.  Insertion is a reach-under: the round mount plate
> overhangs the port by ~17 mm with ~30 mm of vertical headroom.

Your first built arm is **leg 0 = joints 0 / 1 / 2 = servo IDs 2 / 3 /
4**. This doc gets that leg moving safely, then scales to all 18 with a
**distributed-power harness** (§6) that keeps any one connector from
melting.

---

## 0. Why bench power before the battery

A charged 3S LiPo is a ~12 V, many-amp source with no current limit — a
wiring mistake dumps all of it into a short (smoke, burnt traces, or a
slammed servo). A bench supply lets you **set a current limit** so a
mistake trips the supply instead of cooking hardware. Only move to the
LiPo once everything below passes on the bench.

If you don't own a bench supply: at minimum put an **inline fuse**
(~5 A for one leg, the **15–20 A main fuse** of §6 for all 18) on the
servo V+ rail and keep first power-ons short — but a current-limited
supply is strongly preferred for bring-up.

> **Voltage note:** the STS3215-30kg is the **12 V** variant (range
> 6–12.6 V). Run the bus at **12 V** (bench supply, later a 3S LiPo at
> 11.1 V nominal / 12.6 V full). There is **no servo BEC** and **no
> external buck** — the raw 3S rail goes to the Wago→servo path, and a
> separate battery tap feeds the Uno Q (its on-board regulator).

---

## 1. Two power domains (share ground only)

Aug 2026 as-built: **no external buck, no PDB**. Battery → trunk Wagos →
servos, and battery → Uno Q, are separate feeds that share ground only.

```
   BENCH SUPPLY (set 12.0 V, limit 2 A for one leg)   ← swap in 3S LiPo later
            │
            ├─► central trunk Wagos (V+/GND pair of 5-port 221-415) ─► corner POWER Wago pairs (12V+G) ─► per-leg branches
            │         (V+/GND injected per leg, NOT chained leg-to-leg)
            │
            └─► Uno Q VIN (on-board regulator; own battery tap)

   DATA:  Uno Q ─sig+GND─► underside DATA Wagos (near yaw retainers)
              ─► yaw→hip→knee … (signal+GND chained; V+ fed per leg)

   DECK:  magnet hex plate (Uno Q + breakout)
          + raised platform (screen on top)
          + MPU glued on chassis_top (beside the trunk Wagos, near centre)
          MPU ──I²C──► Uno Q  (Stage F)

   ground common (LiPo −, trunk-Wago GND, Uno Q GND, adapter GND, IMU GND)
```

- **Servo power** (12 V) comes from the **central trunk Wago splice
  pair** — two **5-port Wago 221-415** side by side at the chassis_top
  centre (one V+, one GND) — then the **corner power Wago pairs** — one V+/GND pair of 3-port
  221-413 seated between tray walls printed into the chassis_bottom
  top face at each hex corner flat (between adjacent yaw cradles,
  entries facing inward; late-Aug 2026 — no separate tray part) —
  then **per-leg branches** in heavy
  silicone. Power is **not** passed leg-to-leg through the thin servo
  connector pins (see §6).
- **Uno Q power** is a **separate battery tap** (no buck on the servo
  rail). On the bench you can still USB-power the board.
- **Data** is one half-duplex TTL signal, daisy-chained servo to servo.
  On the robot, data jumpers land at **underside data Wagos** near the
  yaw retainers. Preferred path is the MCU `feetech_bridge`; USB adapter
  is the fallback (§ intro / §2).
- **All grounds common**: bench-supply − (or LiPo −), trunk-Wago GND,
  Uno Q GND, adapter GND, IMU GND. Verify with a continuity beep.
- On the bench (one leg) you may feed 12 V into the adapter's power
  terminal; on the full robot the adapter (if used) is **data-only**
  and each leg gets 12 V from the trunk / power Wagos (see §2 and §6).
- **The IMU is on the Uno Q's I²C bus**, glued on chassis_top just
  south of the central trunk Wagos (inboard, header row facing the
  open -X deck so its wires have room; not under the raised platform).
  Totally separate from the servo bus; see Stage F.

---

## 2. The serial bus — Uno Q ↔ bus-servo adapter ↔ servos (DATA)

There is exactly **one** data signal on the robot: the half-duplex TTL
bus, daisy-chained servo to servo. As-built it reaches the Uno Q over a
**3-wire TX/RX/GND pigtail** from the MCU's **D0/D1** pins to the
adapter's UART/MCU header (`feetech_bridge` sketch, § intro); the USB
OTG hookup is a bench-only fallback (and does not work on VIN power —
see the ⚠ note in § intro). No I²C on the servos, no per-servo PWM
lines.

```
  Uno Q ─D1/D0 TX/RX+GND─► adapter ─TTL (1 Mbps)─► ID1 ─► ID2 ─► … ─► ID18
       │  (feetech_bridge MCU UART)  half-duplex, single signal + common GND
       └──I²C (separate bus)──► MPU-6050 IMU

  (bench fallback: Uno Q ─USB-C OTG/powered hub─► adapter, jumper B)
```

- The STS3215 bus is **half-duplex** (one signal wire, TX and RX
  shared). You do **not** hand-wire TX/RX: the USB adapter does the
  direction switching in hardware. You only connect the adapter's servo
  header to the bus — **`D` → Signal, `G` → GND** (and `V` = servo 12 V,
  but read the power note below before wiring `V`).
- **Adapter mode/level settings** (this is the "5 V or 3 V?" question):
  - **FE-URT-2 / FE-URT-1** have a **3.3 V / 5 V logic-level slide
    switch** for the TTL signal. STS/SCS TTL servos use a **5 V** bus —
    set the switch to **5 V**. Plug the servo chain into the **TTL-BUS**
    port (not the RS485 port, which is for SMS servos).
  - **Waveshare Bus Servo Adapter (A)** has no voltage switch; it has an
    **A/B mode jumper** — as-built set it to **A (UART)**: the Uno Q's
    D0/D1 pigtail lands on the UART/MCU header.  **B (USB)** is only for
    the bench USB fallback.
  - **Neither switch sets the servo supply.** The 3.3/5 V logic level is
    the *signal* voltage only. Servo **power** is a separate **12 V**
    rail (matched to the STS3215's 9–12.6 V range), **never** 5 V or 3 V.
- **How servo power reaches the bus** (keep §6 distributed-power intact):
  - **Bench, one leg** (Stages C–E): simplest to feed **12 V** into the
    adapter's screw terminal and let `V` pass to that one leg through the
    servo header (one leg ≈ 1.5–3.7 A, under the adapter's ~5–6 A limit).
  - **Full 18-servo robot** (§6): do **not** route servo power through
    the adapter — it can't carry 18 servos. Use the adapter for **`D` +
    `G` only**; inject each leg's 12 V per-leg from the **bus bar**.
    Leave the adapter's power terminal unpowered (or a low-current 12 V
    reference tap). Either way, common ground is mandatory.
- The host port enumerates as **`/dev/ttyUSB0`** on the Uno Q's Linux
  side (CH340-based FE-URT-1). A CH343-based board (FE-URT-2 / Waveshare)
  may instead show as `/dev/ttyUSB0` or `/dev/ttyCH343USB0` depending on
  the kernel driver — just find it with `ls /dev/ttyUSB* /dev/ttyACM*`
  and pass that to `--port`.
- **12 V must be present on the bus** for the servos to talk (the STS
  logic is powered from V+). Power the rail before scanning.
- Default servo baud is **1 Mbps**; `feetech_bus.py` uses that.

### Install the driver (once, on the Uno Q / laptop)

```bash
python -m pip install feetech-servo-sdk pyserial
```

### Assign servo IDs (once per servo — CRITICAL)

Every servo ships as **ID 1**. A bus needs unique IDs, so you re-ID each
one as you add it. **ID 1 is never assigned to a robot joint** — leaving
the factory default free means a fresh servo can always join a live
daisy-chain without colliding. Prefer the naming wizard
(`motor_setup/urt2_motor_setup.py`) — plug in a servo, watch it wiggle,
then assign any open joint (`L2 knee`, menu pick, …).

```bash
# Free-form labeling (any order):
python ../motor_setup/urt2_motor_setup.py

# Or by hand: connect a factory servo (ID 1) and give it its robot ID:
python ../motor_setup/feetech_bus.py --port /dev/ttyUSB0 setid --from 1 --to 4   # joint 2 (knee), leg 0
```

Logical joint → servo ID is **ID = joint + 2** (IDs 2..19;
`joint = leg*3 + axis`, axis 0=yaw, 1=hip, 2=knee):

| Leg | yaw (axis0) | hip (axis1) | knee (axis2) |
|----:|:---:|:---:|:---:|
| 0 | ID 2 | ID 3 | ID 4 |
| 1 | ID 5 | ID 6 | ID 7 |
| 2 | ID 8 | ID 9 | ID 10 |
| 3 | ID 11 | ID 12 | ID 13 |
| 4 | ID 14 | ID 15 | ID 16 |
| 5 | ID 17 | ID 18 | ID 19 |

Label each servo as you ID it. After all are chained, verify:

```bash
python ../motor_setup/feetech_bus.py --port /dev/ttyUSB0 scan   # expect IDs 2..19 (not 1)
```

---

## 2b. Where the Arduino Uno Q fits in

The Uno Q **is** the controller — there is no separate microcontroller
in the loop. The only thing between it and the servos is the passive
**USB bus-servo adapter** (a USB↔half-duplex-TTL converter, no CPU). Its
Linux side runs `feetech_bus.py`, which:

- maps the 18 logical joints to servo IDs 2..19 (ID 1 left free),
- enforces the same safe per-axis angle limits in software,
- applies per-joint **trims** (stored in
  `../motor_setup/feetech_trims.json`, since there's no EEPROM),
- sync-writes goal positions and reads back live feedback.

Everything below works identically whether the host is your laptop
(bench) or the Uno Q (on-robot): both talk to the **same USB bus-servo
adapter**, so only `--port` changes.

---

## 3. Servos — leg 0 (your built arm)

| Joint | Axis | Servo ID | Limit (deg) |
|---:|---|:---:|---|
| 0 | yaw | 2 | ±35 |
| 1 | hip pitch | 3 | −80 … +30 |
| 2 | knee | 4 | −20 … +80 |

### Where the wires leave an STS3215 (physical)

Feetech’s STS3215 is **not** a classic hobby-servo with a molded boot on
one short end (that was the old DS3225). On the real part (FEETECH STEP
`STS3215_03a`, Waveshare/SO-ARM mounts, and this project’s retainer /
test-cradle notes):

| Item | Fact |
|---|---|
| Ports | **Two** identical 3-pin bus sockets (daisy in / out) |
| Connector | **Molex 5264 / Mini-SPOX 2.5 mm** (often casually called “JST”) |
| Face | Recessed in the **BACK (idler) face** — opposite the output / disc-horn face |
| Side of that face | **Centre / −X half** of the back (away from the output-offset shaft at +X); the +X half of the back carries the idler hub |
| Exit direction | Cables plug into the back and leave **out the back** (when the servo hangs output-up under the chassis, that is **straight down** through the yaw retainer drop window) |
| Pinout | black → GND · red → V+ (12 V) · white/yellow → Signal |

Both ports are wired in parallel — “in” vs “out” is only harness
tidiness. **But note (§6): the red V+ pin is rated only ~3 A, so do not
let it carry more than one leg’s current.**

BuildViz / CAD note: `hexapod_prototype.WIRE_BOOT_*` and the little box on
`make_servo_body` are a **legacy DS3225-shaped stand-in** kept so some
cradle clearance channels still have a probe target. **Harness routes in
`tools/full_robot_viz_build.py` attach at the real back-face port cluster
above**, not at that +X stub.

---

## 3b. The zero state — how the leg must sit at 0 / 0 / 0

`centre` (and `joint <j> 0`) drives every joint to **0°**. The horns
must be bolted so that **0° corresponds to this pose**, or every angle
you command afterwards is off by the mounting error.

**At 0 / 0 / 0 the whole leg is dead straight and horizontal, pointing
straight out from the body**, with coxa, femur, tibia and foot colinear:

```
   zero state (side view, body at left):

   body | ==coxa== (Y)yaw  ==femur== (H)hip  ==tibia== (K)knee  ==> ● foot
                    axis ↕               axis ↺              axis ↺
        all three links colinear, parallel to the table, foot straight ahead
```

- **yaw = 0** → leg points straight out along its mounting azimuth.
- **hip = 0** → femur horizontal, in line with the coxa.
- **knee = 0** → tibia straight, in line with the femur.

### Which way each axis moves (so you mount horns the right way round)

| Axis (joint) | `+` angle moves the link… | `−` angle moves it… | Range | Stand plant |
|---|---|---|---|---:|
| yaw (j0) | swings horizontally one way | the other way | ±35° | 0° |
| hip pitch (j1) | femur tip **down** | femur tip **up** | -80 … +40° | **+20°** |
| knee pitch (j2)| tibia tip **down** (folds under) | tibia tip **up** | -20 … +150° | **+28°** |

So the **default hardware stand plant (0, +20, +28)** is femur angled
toward the floor with tibia steep (or a learned plant from Calibrate →
Plant height).  CAD / MuJoCo / `sts` RL still use the older crouch
**(0, −25, +60)** — see `RL_PLAN.md` Appendix A (lukas/hexapod-orchestrator).

### Mounting each horn against zero

1. `python ../motor_setup/feetech_bus.py --port /dev/ttyUSB0 centre` —
   the servo holds at count 2048 (its 0° centre).
2. With the servo powered and held at 0°, fit the FEETECH POM horn /
   link so the link sits in the straight-out zero pose above, then bolt
   it (4× M2.5 on the 9.9 mm square pattern + the central M3 horn screw).
3. Get within one spline tooth, bolt it, then null out the rest with a
   software trim: `feetech_bus.py … trim <joint> <deg>` (clamped ±30°).
   e.g. if hip sits 4° high at "0": `trim 1 -4`.
4. Re-run `centre` and confirm all three links are straight and level.

> Trims are saved to **`feetech_trims.json`** and re-applied on every
> command, so you calibrate each joint **once**.

> Unlike the old PWM servos, the STS3215 is **absolute**: it knows its
> angle the instant it powers on (12-bit magnetic encoder), so there is
> no blind centre-on-boot slam — you can `relax` it, pose it by hand,
> and `feedback` will read exactly where it is.

---

## 4. Bench bring-up sequence

Drive everything from `feetech_bus.py`. Common commands:

| Command | Does |
|---|---|
| `scan` | list servo IDs on the bus |
| `setid --from 1 --to N` | re-ID the **only** servo on the bus |
| `centre` | all joints → 0° |
| `joint <j> <deg> [--sweep]` | move one joint (eased with `--sweep`) |
| `wiggle --joint <j>` | direction/range check macro |
| `stance` | full standing pose on all 18 joints |
| `relax [--joint j]` | torque **off** (limp) so you can pose by hand |
| `hold [--joint j]` | torque **on** (hold position) |
| `feedback [--watch]` | position / load / volt / temp / current table |
| `trim <j> <deg>` | set + save a trim offset (±30°) |

Software clamps every command to the safe per-axis limits (yaw ±35, hip
−80…+30, knee −20…+80).

### Stage A — Rail only, nothing else connected
Bench supply set to **12.0 V, current limit 2.0 A**. No servos.

- [ ] Output reads ~12.0 V on the meter.
- [ ] No short between V+ and GND leads (continuity = open).
- [ ] Supply OFF.

### Stage B — Uno Q + USB adapter on the bus, no servos
Uno Q powered **over USB-C** (NOT VIN/battery tap — a VIN-powered Uno Q
gives no USB host mode and no VBUS, § intro ⚠ note); **USB bus-servo
adapter plugged into the Uno Q's USB-C** (mode set per §2: FE-URT-2
level switch → 5 V, or Waveshare jumper → B); 12 V rail still OFF.
On-robot / VIN power, skip the USB stages and use the D0/D1 UART bridge.

- [ ] `ls /dev/ttyUSB* /dev/ttyACM*` shows the adapter's port (note it,
      that's your `--port`).
- [ ] `scan` returns nothing yet (no servos / no power) — that's fine; it
      confirms the port opens.

### Stage C — One spare servo, off the arm
Connect a **spare** STS3215 to the bus signal and the 12 V rail. Supply
ON (12 V / 2 A limit).

```bash
feetech_bus.py --port /dev/ttyUSB0 scan          # expect [1] (factory ID)
feetech_bus.py --port /dev/ttyUSB0 setid --from 1 --to 1
feetech_bus.py --port /dev/ttyUSB0 joint 0 15
feetech_bus.py --port /dev/ttyUSB0 joint 0 -15
feetech_bus.py --port /dev/ttyUSB0 feedback      # reads back ~ -15 deg, volts, temp
```

- [ ] Servo answers `scan`; moves smoothly both ways.
- [ ] `feedback` shows sane volts (~12 V), low load, reasonable temp.
- [ ] Idle/move current well under the 2 A limit.

### Stage D — Leg 0 servos (IDs 2/3/4), one joint at a time
ID the three leg-0 servos (1, 2, 3), chain them, plug into one **per-leg
branch** of the rail. **Clamp the arm, foot in the air.** Current limit
~**3 A**.

```bash
feetech_bus.py --port /dev/ttyUSB0 scan          # expect [1, 2, 3]
feetech_bus.py --port /dev/ttyUSB0 joint 0 20 --sweep    # yaw
feetech_bus.py --port /dev/ttyUSB0 joint 1 -25 --sweep   # hip toward stance
feetech_bus.py --port /dev/ttyUSB0 joint 2 60 --sweep    # knee toward stance
```

- [ ] Each joint moves the **expected direction** (flip `JOINT_SIGN[j]`
      in `feetech_bus.py` if reversed).
- [ ] No mechanical binding before the software limit.
- [ ] Fix offsets with `trim`, not by re-bolting the horn.

### Stage E — Coordinated stance + load

```bash
feetech_bus.py --port /dev/ttyUSB0 stance
feetech_bus.py --port /dev/ttyUSB0 feedback --watch
```

- [ ] Leg settles into a stable stance pose.
- [ ] Hold 30–60 s watching `feedback`: temp climbs modestly, load
      sane, supply not pinned at its limit.

### Stage F — IMU (MCU Wire I²C on SDA/SCL, separate from the servo bus)
The MPU-6050 is **4 wires** from the GY-521 breakout to the Uno Q
**header SDA/SCL (D20/D21)** — STM32 `Wire`, **not** Linux SoC I²C.
Linux `i2cdetect` on `/dev/i2c-*` will **never** show `0x68` for this
wiring; the MCU sketch owns the bus. As-built (Aug 2026): the breakout
is **glued on `chassis_top`** just south of the central trunk Wago pair
(inboard, r = 43), right-angle header row facing the open -X deck so
the four jumpers have clear exit room; short run up to the Uno Q.

| GY-521 pin | → Uno Q | What it is |
|---|---|---|
| `VCC` | **3V3** power (via the 3.3 V Wago under the mount plate) | power — 3V3, **not** 5V |
| `GND` | **GND** | ground |
| `SCL` | **SCL (D21)** | MCU Wire clock |
| `SDA` | **SDA (D20)** | MCU Wire data |
| `AD0` | leave unconnected | sets address `0x68` |
| `XDA`,`XCL`,`INT` | leave unconnected | not used |

> ⚠ **Power the GY-521 from 3V3, never 5V** — its SDA/SCL pull-ups go
> to VCC and 5V would over-drive the 3.3 V I²C lines.
>
> As-built (Aug 2026): the 3.3 V loads splice at a **5-port Wago 221-415
> VHB'd under the round mount plate** (south rim, entries facing the
> rim), fed ONCE from the Uno Q 3V3 pin through the plate's east Ø8 wire
> port — one lever nut is the whole 3.3 V rail.  Current load = GY-521
> VCC only (3 spares): the **screen does NOT tap this Wago** — its whole
> 8-wire pigtail (screen header order: GND VCC SCL SDA RES DC CS BLK)
> runs from the Uno Q up
> the az-330 platform leg and through the 24×5 wire slot in the
> platform's top plate; the panel is held by 4× M2 self-tappers in the
> top plate's corner pilot holes.  Screen pin map (Uno layout, SPI):
> GND → **GND**, VCC → **3V3** (power header), SCL → **D13** (SCK),
> SDA → **D11** (MOSI), CS → **D10**, DC → **D9**, RES → **D8**,
> BLK → **D7**.
>
> Do **not** use A4/A5 for this board's main `Wire` — on Uno Q those are
> not the labeled SDA/SCL header. Qwiic is a second MCU bus (`Wire1`).

Flash / keep [`feetech_bridge`](feetech_bridge/) (commands `I2CSCAN`,
`IMU`, `IMUR`), then on the Uno Q Linux side:

```bash
# after flash_feetech_bridge.sh — probe over /dev/ttyHS1
cd ~/linux_control   # or wherever mpu_probe.py + mcu_feetech_bus.py live
python3 mpu_probe.py
# expect: I2CSCAN → OK 0x68   IMU → OK 0x68   IMUR → OK <ax> ...
```

If `IMU` returns `ERR no_ack`: confirm VCC=**3V3**, GND common, and
SDA→SDA / SCL→SCL (not swapped, not on high-speed 1.8 V headers).

---

## 5. Switching from bench supply to LiPo

Only after Stages A–F pass, build the §6 power harness and then:

1. Bench supply OFF and disconnected.
2. Wire the full §6 harness:
   `3S LiPo XT60 → anti-spark switch → main fuse (15–20 A) → trunk
   Wagos → power Wagos → per-leg branches`, plus a **separate battery
   tap to the Uno Q** (no buck).
3. **Verify common ground** across LiPo −, trunk-Wago GND, Uno Q, IMU.
4. The **anti-spark switch is your e-stop** — keep a hand near it for
   the first powered run.

---

## 6. Distributed-power harness (all 18 servos)

This is the heart of the full-robot wiring. **Read it before you chain
all 18 servos to one rail.**

> This whole section is also rendered as a WireViz diagram —
> [`harness.svg`](harness.svg) (regenerate with
> `../scripts/render_harness_diagram.py`). The per-leg branch lengths in
> it come from the geometry-derived `../motor_setup/wire_harness_plan.py`.

### 6.1 Why you cannot daisy-chain power

The FEETECH 3-pin bus cable is **22–24 AWG with Molex 5264 /
Mini-SPOX 2.5 mm** connectors rated only **~3 A per pin**. Data is
fine over that (milliamps). **Power is not.**

If you chain all 18 servos' **power** through one bus, the **first
segment carries the sum of everything downstream**:

| Load case | Current the upstream pin sees |
|---|---:|
| Idle (18 × ~0.2 A) | ~3.6 A  — already over 3 A |
| Walking (18 × ~0.5 A) | ~9 A — 3× the pin rating |
| Several servos stalling at once | up to **~49 A** (18 × 2.7 A)  |

A 9 A continuous draw through a 3 A pin **melts the upstream 5264
connector**. So **DATA stays chained; POWER must be DISTRIBUTED** so no
single 5264 pin ever carries more than **one leg** (~1.5 A walking,
with stall headroom).

### 6.2 Architecture

```
  3S LiPo (11.1 V nom / 12.6 V full)
     │  XT60
     ├──────────────────────────────────────► Uno Q VIN  (own tap; no buck)
     ▼
  ANTI-SPARK SWITCH  (precharge + on/off = e-stop)
     │  XT60 → 12–14 AWG silicone
     ▼
  MAIN FUSE  15–20 A  (blade/ANL in holder)
     │  12–14 AWG silicone
     ▼
  ┌──────────  TRUNK WAGOS (V+ nut + GND nut, chassis_top)  ──────────┐
  │  (V+ splice)                                        (GND splice)  │
  │   ├─► chassis-top POWER Wago (12V+G) ─► leg 0 branch …
  │   ├─► chassis-top POWER Wago (12V+G) ─► leg 1 branch …
  │   ├─► … one Wago + branch per leg …
  │   └─► chassis-top POWER Wago (12V+G) ─► leg 5 branch …
  └────────────────────────────────────────────────────────────────────┘
  (as-built Aug 2026: no PDB — the whole distribution is Wago 221 lever nuts)

  DECK (magnet hex + raised platform):
      4× posts at CHASSIS_STANDOFF_HOLES_XY (±31.1):
         20 mm standoff + ~2.5 mm M3 thumb nut + Ø8×8 mm magnet
      → round_mount_plate_115 (Uno Q + breakout on top; 3.3 V Wago under)
      → hex_raised_platform_110 (screen on top)
      → MPU-6050 glued on chassis_top (beside trunk Wagos, near centre)

  DATA (separate, low current) — underside DATA Wagos near yaw retainers;
  **as-built entry is at each yaw**:
  Uno Q ─sig+GND─► data Wagos ─►
      ┌─► L0 yaw ─► L0 hip ─► L0 knee ─┐
      │   (leg 0 data through the leg)  │  leg-to-leg = SIGNAL+GND only
      ├─► L1 yaw ─► L1 hip ─► L1 knee ─┤  (no V+ between legs)
      ├─► …                            │
      └─► L5 yaw ─► L5 hip ─► L5 knee ─┘

  POWER (per-leg trunk-Wago branch) — **as-built inject at each hip**:
      power Wago ─V+/GND─► L? hip ─┬─► L? yaw
                                  └─► L? knee
      (hip is the power tee; yaw/knee take V+ from the hip, not from
       the chassis branch directly)

  LiPo velcro under chassis; data Wagos under chassis near yaw retainers.
```

**As-built per-leg topology (Aug 2026 bench build):**

| Rail | Enters the leg at | Then goes |
|---|---|---|
| **DATA** (signal + GND) | **yaw** first | yaw → hip → knee (out through the leg), then leg-to-leg jumper to the next yaw |
| **POWER** (V+ / GND) | **hip** (bus-bar branch) | hip → yaw and hip → knee |

Diagnostic consequence: a yaw that **blinks (has V+)** but **does not answer** usually still has power via the hip tee, while its **DATA in** (chassis → yaw) or the yaw UART is dead. Hip/knee on that leg may still answer if they remain on the data chain past a deaf yaw — or drop off entirely if the chain is broken at that yaw.

**The two rules that prevent the melt:**

1. **Within a leg** (3 servos): keep the stock 3-pin chain for DATA
   (and local V+ after the hip inject). The leg's bus-bar branch
   injects **at the hip** so the chassis 5264 only feeds that tee;
   yaw and knee draw through the hip's second port / harness tee
   (still one leg's current on the branch — under the 3 A rating).
2. **Leg-to-leg**: the cable that continues the DATA chain to the next
   leg carries **Signal + GND only** — **cut/omit the V+ wire**. Each
   leg already has its own V+ feed from the trunk / power Wago at the hip,
   so power never bridges between legs and no pin ever carries more than
   one leg.

### 6.2.1 Fat power wires vs DATA (signal integrity)

The STS bus is **1 Mbps half-duplex TTL** — easy to upset. Thick V+/GND
leads are fine electrically for current, but if they **run parallel /
bundled** with the thin DATA line for more than a short hop they can
couple switching noise (motor PWM / load steps) into the signal and
make one servo look “deaf” (LED still blinks from V+, scan misses it)
or flaky.

Practical rules for this as-built topology:

- Keep the **hip power branch** (thick wire) **physically apart** from
  the **yaw data in** lead; cross at ~90° if they must meet, don’t
  zip-tie them side-by-side along the coxa.
- DATA should travel as **signal + its own GND pair** (twisted if you
  extend it). Do **not** rely on the fat power GND alone as the UART
  return over a long run — motor return current on that GND shifts the
  logic reference.
- Short stock 3-pin pigtails yaw↔hip↔knee are usually OK even with
  local V+ in the same plug; trouble shows up on **long chassis→yaw
  data runs** laid next to the bus-bar branch.
- Quick A/B test: temporarily route a **short, separate** signal+GND
  only into that yaw (power still from the hip). If it suddenly
  answers, the thick parallel power run was the culprit — not the
  servo.
- Optional: try `--baud 500000` (or 115200) once; if a “missing” yaw
  appears only at lower baud, treat it as noise/edge-rate until the
  layout is cleaned up, then return to 1 Mbps.

### 6.2.2 Adding legs one at a time (bring-up)

The bus often looks fine with 1–3 legs and then misbehaves when the
**4th** data stub goes on: extra cable capacitance + another yaw tap at
1 Mbps, or a bad **leg-to-leg** jumper (especially if V+ was left
connected on a “data-only” cable).

Bring-up rule:

1. Confirm scan with N legs.
2. Add leg N+1 **data** only after its power branch is sane; prefer not
   hot-plugging the data jumper under a heavy load.
3. If something that used to answer goes offline (e.g. L0 yaw LED blinks
   but scan misses it): **unplug the newest leg’s data jumper first**.
   If the old motors return, the newest stub/jumper is guilty — not the
   yaw servo itself.
4. Test the newest leg **alone** on the URT-2; then 3 good legs; then
   add the 4th.
5. Interactive checklist: `urt2_motor_setup.py --debug` → “new leg broke
   the bus” bring-up.

The "bus bar" is implemented as a **central trunk Wago splice pair**
(as-built Aug 2026 — an earlier revision spec'd a Matek PDB-XT60 drone
power-distribution board; the build dropped it): two **5-port Wago
221-415** side by side at the chassis_top centre — one splices the
fused V+ trunk into the branch feeds, the other splices GND (each nut:
1 trunk port in + 4 branch ports; share ports across the six branches
as wired).  **Polarity convention: V+ = the SOUTH nut (−Y, nearest the
switch), GND = the NORTH nut.**  At each corner tray the convention is
**V+ = the nut clockwise of the corner's outward ray, GND =
counterclockwise** (viewed from above; same at every corner, so a
red/black pair never crosses inside a tray).  A Wago 221 is rated 32 A / 4 mm² — well above the ~13 A
walking trunk.  From the trunk pair, land each motor branch on its leg's
**corner power Wago pair** (12 V+G; two 3-port 221-413 seated in the
tray walls printed into chassis_bottom at the hex corner) before the leg
harness.  The Uno Q
takes a **direct battery tap** (no external buck).  The optional
per-branch fuses (5–7 A) protect each leg's thin harness against a
multi-servo stall in that leg.

### 6.3 Per-branch current budget

STS3215 @ 12 V: idle ~0.2 A, walking ~0.3–0.7 A/servo, peak/loaded
~1–2 A, stall 2.7 A.

| Branch | Servos | Idle  | Walking (typ) | Walking (high) | 1 servo stall* | Wire | Fuse |
|---|:---:|---:|---:|---:|---:|---|---|
| Leg 0 (ID 2/3/4) | 3 | 0.6 A | ~1.5 A | ~2.1 A | ~3.7 A | 16–18 AWG | opt 5–7 A |
| Leg 1 (ID 5/6/7) | 3 | 0.6 A | ~1.5 A | ~2.1 A | ~3.7 A | 16–18 AWG | opt 5–7 A |
| Leg 2 (ID 8/9/10) | 3 | 0.6 A | ~1.5 A | ~2.1 A | ~3.7 A | 16–18 AWG | opt 5–7 A |
| Leg 3 (ID 11/12/13) | 3 | 0.6 A | ~1.5 A | ~2.1 A | ~3.7 A | 16–18 AWG | opt 5–7 A |
| Leg 4 (ID 14/15/16) | 3 | 0.6 A | ~1.5 A | ~2.1 A | ~3.7 A | 16–18 AWG | opt 5–7 A |
| Leg 5 (ID 17/18/19) | 3 | 0.6 A | ~1.5 A | ~2.1 A | ~3.7 A | 16–18 AWG | opt 5–7 A |
| Logic (Uno Q battery tap)| — | ~0.3–0.5 A (board) | | | | 20–22 AWG | (board) |
| **Main trunk (sum)**  | **18** | ~3.6 A| **~9 A** | **~12.6 A** | (stalls add) | 12–14 AWG | **15–20 A** |

\* "1 servo stall" = one servo of the leg at 2.7 A stall while the
other two walk (~0.5 A each). A whole-leg 3-servo stall is ~8 A and is
what the optional 5–7 A branch fuse is there to catch on a sustained
jam. The 15–20 A main fuse protects the trunk; it is sized above the
~9–12.6 A walking draw and below a dead-short, not to ride out an
all-18 multi-stall (which the controller's torque limits should
prevent anyway).

### 6.4 Wire & connector summary

| Run | Gauge / part | Carries |
|---|---|---|
| LiPo → switch → fuse → trunk Wagos | **12–14 AWG silicone** (XT60 pigtails)  | full robot ~9–13 A |
| Trunk Wagos → power Wago → per-leg branch | **16–18 AWG silicone** + Wago 221 | one leg ~1.5–3.7 A |
| Branch → leg first servo | **Molex 5264 3-pin pigtail** (crimped) | one leg |
| Within-leg servo-to-servo | stock FEETECH 3-pin (22–24 AWG, 5264) | one leg |
| Leg-to-leg (DATA only) | 2-wire signal+GND via underside data Wagos — **no V+** | signal (mA) |
| LiPo → Uno Q VIN | 20–22 AWG (separate battery tap) | Uno Q (~0.3–0.5 A) |
| Uno Q USB-C → USB adapter (fallback) | USB-C-to-C + **USB-C OTG/hub** | USB data |
| USB adapter `D`/`G` → bus | 2-wire signal+GND (22–24 AWG) — **no V+** | signal (mA) |

> **Common ground is mandatory.** The trunk-Wago GND, the Uno Q GND, and
> the **USB adapter's servo-power GND** (if used) must all be bonded, or
> the half-duplex signal has no return reference and the bus goes
> silent/garbled. (USB already shares GND between the Uno Q and the
> adapter's logic side; the point here is the adapter's **12 V servo
> terminal GND** must also tie to the trunk-Wago GND.)

### 6.5 Simulated stand-up draw (MuJoCo, Jul 2026)

`../standup_current_sim.py` simulates the robot standing up from a
belly-down, legs-folded pose in the `mujoco_prototype.py` model and
converts net joint torques to bus current with the STS3215 electrical
model at 12 V (`I = 0.2 A idle + 2.5 A × |τ|/2.94 N·m`, capped at the
2.7 A stall).  Realistic-mass case = 2.89 kg total (1.30 kg chassis
subtree: plates + yaw servos + the battery — now 2 × 137 g shorty
LiPos under the belly, ~same mass as the retired 300 g bay pack —
+ Wagos/Uno Q/hex deck), servo gains ×5 to approximate the real PID.

| Quantity | Gentle stand-up (1.5 s) | Fast stand-up (0.4 s) | Budget limit |
|---|---|---|---|
| Trunk peak (instantaneous) | 12.5 A | 16.7 A | — (≪100 ms spike; fuses ignore it) |
| Trunk peak (100 ms avg) | 12.5 A | 12.2 A | 15–20 A main fuse |
| Standing hold (steady) | 10.3 A | 10.3 A | ~9–13 A walking budget (§6.3) |
| Worst leg branch peak | 2.1 A  | 3.0 A  | 5–7 A branch fuse, 32 A Wago joint |
| Worst single-servo torque  | 1.1 N·m| 2.1 N·m| 2.94 N·m stall |

Verdict (all within budget):

- The robot stands and stays upright in every mass case; the stiff-gain
  case reaches ~81 % of stance height (remaining sag is pure-P droop in
  the sim — the real servo's integral term closes it).
- Branch fuses, 16–18 AWG branch wire, and the 32 A Wago 221 joints all
  carry ≥2× margin over the worst simulated leg (3.0 A).
- **Fit a 20 A main fuse** (top of the §6.3 range): a fast stand-up
  spikes to 16.7 A for ~50 ms.  Blade fuses need sustained ~135 % of
  rating for seconds to open, so even 15 A survives it, but 20 A means
  a hard stand-up plus a stumble never nuisance-blows the trunk.
- Ramp the stand-up over ≥1 s in firmware: it halves the worst knee
  torque (2.1 → 1.1 N·m) and keeps every servo far from stall.
- Runtime at the ~10.3 A hold: ~13 min on one 2200 mAh 3S, ~26 min on
  the as-built pair of paralleled 2200 mAh shorty packs (4400 mAh).
- Caveat: the linear torque→current model is conservative for static
  holds — a geared STS3215 parked inside its deadband draws less, so
  real standing draw should land at or below these figures.

Re-run `PYTHONPATH=. python standup_current_sim.py --fast` and refresh
this table whenever masses, servo gains, or leg geometry change.

---

## Per-joint log (fill in for all 6 legs)

| Joint | ID | Neutral | Safe min | Safe max | Dir (`JOINT_SIGN`) | Binds at | Notes |
|---:|---:|---:|---:|---:|---|---|---|
| 0 yaw | 1  | 0 | | | | | |
| 1 hip | 2  | −25 | | | | | |
| 2 knee| 3  | +60 | | | | | |

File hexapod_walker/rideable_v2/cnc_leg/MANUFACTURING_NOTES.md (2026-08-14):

# rideable_v2 — one-leg CNC order (chain variant)

Generated by `tools/export_leg_cnc.py` — regenerate, don't hand-edit.
STEP solids of every custom machined part for ONE leg
([`CHAIN_VARIANT.md`](../CHAIN_VARIANT.md)); intended for a Xometry
CNC order while the Carvera is in transit. DXFs of the flat plates
are in `dxf/` for later Carvera CAM (or a waterjet fallback).

## Order table

| STEP | Qty | Material | Status |
|---|---:|---|---|
| `hip_tooth_plate_52T.step` | 2 | 7075-T6 | release now |
| `hip_spacer_ring.step` | 1 | 7075-T6 | release now |
| `hip_standoff_ring.step` | 1 | 7075-T6 | release now |
| `hip_lock_hub_disc.step` | 1 | 7075-T6 | release now |
| `knee_tooth_plate_42T.step` | 2 | 7075-T6 | release now |
| `knee_spacer_ring.step` | 1 | 7075-T6 | release now |
| `knee_standoff_ring.step` | 1 | 7075-T6 | release now |
| `knee_lock_hub_disc.step` | 1 | 7075-T6 | release now |
| `yaw_tooth_plate_36T.step` | 2 | 7075-T6 | release now |
| `yaw_spacer_ring.step` | 1 | 7075-T6 | release now |
| `yaw_standoff_ring.step` | 1 | 7075-T6 | release now |
| `yaw_hub_disc.step` | 1 | 7075-T6 | release now |
| `tensioner_arm.step` | 3 | 6061-T6 | release now |
| `femur_hub.step` | 1 | 6061-T6 | **HOLD** until print-kit assembly check passes |
| `tibia_hub.step` | 1 | 6061-T6 | **HOLD** until print-kit assembly check passes |
| `coxa_clevis.step` | 1 | 6061-T6 | **HOLD** until print-kit assembly check passes |
| `lock_clevis.step` | 2 | 6061-T6 | **HOLD** until print-kit assembly check passes |

`motor_mount_plate` is deliberately NOT here: its AK80-64 bolt
pattern is a placeholder. Verify against the CubeMars STEP, update
`export_leg_test_prints.py`, print-check, then machine.

## Critical callouts (attach to the Xometry quote)

- Default tolerance ISO 2768-m is fine everywhere EXCEPT:
- Lock/hub discs: 24x Ø18 lock-ring bores — press fit for hardened
  bushings: Ø18.00 +0.00/-0.03 (S7-class).
- Coxa clevis: Ø52 bearing bore — press seat for 30205 cups:
  Ø52.00 +0.00/-0.03, both cups from the same bore, back-to-back.
- Femur/tibia hubs: Ø25 shaft bore — H7 (+0.021/0), ream or bore.
- Tooth plates: profile is the exact ANSI B29.1 form — machine the
  outline as-modeled, no added offset; deburr both faces.
- Dowel holes Ø6.1: as-machined is fine (slip fit over Ø6 dowels).
- Tooth plates + spacers + discs of one joint are a matched stack:
  ask for them deburred flat (no protruding burrs on mating faces).

## Material notes

- 7075-T6 for tooth plates (wear), spacers and discs may be quoted
  6061-T6 to save cost with no structural issue.
- Hubs/clevises 6061-T6 per the FEA basis (`tools/fea_leg_nodes.py`).

## Sanity numbers (pinned by tools/sprocket_profile.py)

- 52T: PD 210.3 / OD 217.6; 42T: PD 169.9 / OD 177.1;
  36T: PD 145.7 / OD 152.8; seat R 4.018 (#40, Dr 7.92).

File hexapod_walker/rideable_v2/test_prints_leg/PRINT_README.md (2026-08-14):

# rideable_v2 — one-leg test-print kit (chain variant)

Generated by `tools/export_leg_test_prints.py` — regenerate, don't
hand-edit. GEOMETRY/FIT articles only: printed sprockets take tens
of N·m (moving an unloaded leg), never the bench-rig load
([`CHAIN_VARIANT.md`](../CHAIN_VARIANT.md) §8).

**Xometry settings:** MJF PA12 or SLS Nylon 12, no finish needed.
Sprocket teeth use the full ANSI B29.1 form (built-in seat
clearance). For home FDM regenerate with PRINT_OFFSET ~0.1 mm.
Print tooth plates flat.

**What the print validates:** ANSI tooth mesh with real #40-2 chain
(same contour the Carvera later mills), duplex row spacing + dowel
clocking, lock-pin ring + clevis + solenoid throw, hub bolt-up,
chain routing/tensioner/guard clearance on the leg.

**Known placeholder:** the motor-mount bolt pattern (8x M5 on
Ø90 BCD) — verify against the AK80-64 STEP before trusting it.

| STL | Qty (one leg) | Envelope (mm) |
|---|---:|---|
| `hip_tooth_plate_52T.stl` | 2 | 217 x 217 x 6 |
| `hip_spacer_ring.stl` | 1 | 194 x 194 x 8 |
| `hip_standoff_ring.stl` | 1 | 194 x 194 x 5 |
| `hip_lock_hub_disc.stl` | 1 | 210 x 210 x 12 |
| `knee_tooth_plate_42T.stl` | 2 | 177 x 177 x 6 |
| `knee_spacer_ring.stl` | 1 | 154 x 154 x 8 |
| `knee_standoff_ring.stl` | 1 | 154 x 154 x 5 |
| `knee_lock_hub_disc.stl` | 1 | 210 x 210 x 12 |
| `yaw_tooth_plate_36T.stl` | 2 | 152 x 152 x 6 |
| `yaw_spacer_ring.stl` | 1 | 130 x 130 x 8 |
| `yaw_standoff_ring.stl` | 1 | 130 x 130 x 5 |
| `yaw_hub_disc.stl` | 1 | 160 x 160 x 12 |
| `femur_hub.stl` | 1 | 240 x 90 x 100 |
| `tibia_hub.stl` | 1 | 140 x 75 x 100 |
| `coxa_clevis.stl` | 1 | 225 x 40 x 90 |
| `motor_mount_plate.stl` | 3 | 130 x 130 x 12 |
| `lock_clevis.stl` | 2 | 70 x 36 x 56 |
| `tensioner_arm.stl` | 3 | 130 x 30 x 6 |

Buy-not-print for the same test: #40-2 chain loop + master links,
stock 13T/14T/18T drivers, 15T idlers, Ø12 dowel pin, die spring,
solenoid, M8 hardware ([`CHAIN_VARIANT.md`](../CHAIN_VARIANT.md) §7).

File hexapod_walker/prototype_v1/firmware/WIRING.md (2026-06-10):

# Hexapod prototype — wiring & bench bring-up

One-page checklist for wiring the electronics and testing them **on a
bench power supply first**, before the LiPo is ever connected. Pair
this with the firmware in `prototype_servo_bridge/` and the client in
`../pi_control/servo_bridge_client.py`.

Your first built arm is **leg 0 = joints 0 / 1 / 2**, all on PCA9685
`0x40`, channels 0 / 1 / 2, stock DS3225 pigtails (no extensions). This
doc gets that leg moving safely.

**You do not need the Raspberry Pi for any of this.** The whole servo
bench test runs on just the **Arduino Mega + your laptop** (USB serial).
The Pi is only involved in the very last step (the IMU), which is on a
separate I²C bus — see Stage F.

---

## 0. Why bench power before the battery

A charged 3S LiPo is a ~12 V, many-amp source with no current limit —
a wiring mistake dumps all of it into a short (smoke, burnt traces, or
a slammed servo). A bench supply lets you **set a current limit** so a
mistake trips the supply instead of cooking hardware. Only move to the
LiPo once everything below passes on the bench.

If you don't own a bench supply: at minimum put an **inline fuse**
(~5 A) on the servo rail and keep first power-ons short, but a
current-limited supply is strongly preferred for bring-up.

---

## 1. Two power domains (share ground only)

```
   BENCH SUPPLY (set 5.5V, limit 2A)        ← swap in LiPo+BEC later
            │
   ┌────────┴────────┐
   │                 │
 PCA 0x40 V+      (PCA 0x41 V+)             ← servo power, NOT from Arduino
 servo rail        servo rail

   Arduino Mega  ── 5V / GND / SDA / SCL ──► PCA 0x40 (+ PCA 0x41 later)
        │   (Mega is the I²C master for the PCA boards)
       USB ──► laptop (logic power + serial during bench test)

   MPU-6050 IMU ── separate bus ──► Raspberry Pi GPIO I²C  (Stage F only)
```

- **Logic** (Mega, PCA9685 VCC) is powered from the Mega's USB on the
  bench — clean and current-limited by the laptop port. No Pi needed.
- **Servo V+** comes only from the bench supply (later: the BECs) into
  the PCA9685 **screw terminals**. Never power DS3225s from the Mega
  5V pin (firmware header, lines 39–41).
- **All grounds common**: bench-supply −, PCA V+ terminal GND, PCA
  logic GND, Mega GND. Verify with a continuity beep.
- **The IMU is NOT on the Mega's bus.** It rides the Pi's I²C bus and
  is read by the Pi directly — the servo firmware never touches it. It
  plays no part in the arm test; see Stage F.

---

## 2. I²C control bus — Mega ↔ PCA9685 (Mega is the master)

The **Arduino Mega is the I²C master** for the PCA boards (the firmware
does `Wire.begin()` / `pwm.begin()`). The PCAs hang off the Mega's pins
20/21 — **not** the Pi or laptop. That's why you verify them with a
scanner *sketch* on the Mega, not with `i2cdetect` (which only scans a
Linux host's own bus, and your laptop doesn't have one).

| Mega pin | PCA9685 #1 (0x40) | PCA9685 #2 (0x41, later) |
|---|---|---|
| `SDA` (pin 20)  | SDA | SDA (chain) |
| `SCL` (pin 21)  | SCL | SCL (chain) |
| `5V` | VCC (logic) | VCC (logic) |
| `GND` | GND (logic) | GND (logic) |

- For the single-arm bench test you only wire **board `0x40`**. Board
  `0x41` comes later (it only carries joints 16 & 17 = leg 5 hip+knee).
- Daisy-chain board #2 from board #1's pass-through header, or run
  separate jumpers from the Mega.
- **Solder the `A0` pad on board #2** so it enumerates as `0x41`.
  Board #1 stays unjumpered (`0x40`).
- VCC (logic, ~5 V low current) is **separate** from the V+ servo
  terminal block — don't bridge them.

**Verify the Mega sees the board(s)** with this scanner sketch, read in
the Arduino serial monitor @ `115200`, then re-flash the real firmware:

```cpp
#include <Wire.h>
void setup() {
  Serial.begin(115200);
  Wire.begin();
  Serial.println("Scanning I2C...");
  for (byte a = 1; a < 127; a++) {
    Wire.beginTransmission(a);
    if (Wire.endTransmission() == 0) {
      Serial.print("found 0x"); Serial.println(a, HEX);
    }
  }
}
void loop() {}
```

Expect `0x40` (and `0x41` once that board's `A0` jumper is set).

---

## 2b. Where the Raspberry Pi fits in (USB, **not** I²C)

Short answer: **you never connect the Pi to the PCA's SDA/SCL.** The
PCA boards stay on the Arduino's I²C bus, and the Arduino is their only
master. The Pi connects to the **Arduino over USB** and sends the same
text commands you typed by hand (`C`, `J 0 20`, …). The Arduino is a
"servo bridge": Pi decides *what* pose, Arduino does the real-time PWM.

```
  Raspberry Pi ──USB cable──► Arduino Mega ──I²C (pins 20/21)──► PCA 0x40 / 0x41 ──► servos
       │           (serial,           (Mega = I²C master)
       │            115200)
       └──I²C (GPIO2/3, its OWN bus)──► MPU-6050 IMU
```

Two separate I²C buses, one per processor — they are **not** joined:

- **Arduino's bus** (Mega pins 20/21): the two PCA9685 boards. Mega is
  master.
- **Pi's bus** (Pi GPIO2 `SDA` / GPIO3 `SCL`): the MPU-6050 only. Pi is
  master.

> ⚠ **Do not wire the Pi's SDA/SCL to the Arduino's SDA/SCL.** That
> would put two masters on one bus and they'd fight. The Pi↔Arduino
> link is USB serial, full stop.

### How to talk to the Arduino from the Pi

It's the *exact same serial protocol* you've been typing — the Pi just
sends those lines over the USB cable instead of you typing them. The
repo's client already does this:

```bash
# On the Pi (after: python -m pip install pyserial):
python hexapod_walker/prototype/pi_control/servo_bridge_client.py \
    --port /dev/ttyACM0 centre
python hexapod_walker/prototype/pi_control/servo_bridge_client.py \
    --port /dev/ttyACM0 joint 1 20 --sweep
```

- The Arduino enumerates on the Pi as **`/dev/ttyACM0`** (or
  `/dev/ttyUSB0` on some clones). Find it with `ls /dev/ttyACM* /dev/ttyUSB*`.
- This is the only wire between Pi and Arduino: the **USB-A → USB-B
  cable** from the BOM. Power-wise the Pi can power the Mega over that
  cable, but on the robot give each its own supply (see §5).
- Everything in Stages C–E works identically whether the serial host is
  your laptop (bench) or the Pi (on-robot) — only the `--port` changes.

### Division of labor (why two processors)

- **Arduino Mega**: real-time servo PWM via the PCAs, hard angle-limit
  clamping, trim. Deterministic, never blocked by an OS.
- **Raspberry Pi**: high-level brain — gait planner, vision, Wi-Fi, and
  reading the IMU on its own bus. Streams pose vectors (`A <18 floats>`)
  to the Arduino over USB.

---

## 3. Servos — leg 0 (your built arm)

All three land on PCA `0x40`. Source of truth:
`python -m hexapod_walker.prototype.pi_control.wire_harness_plan`.

| Joint | Axis | Board | Ch | Cable | Limit (deg) |
|---:|---|---|---:|---|---|
| 0 | yaw | 0x40  | 0  | stock pigtail  | ±35 |
| 1 | hip pitch | 0x40  | 1  | stock pigtail  | −80 … +30 |
| 2 | knee | 0x40  | 2  | stock pigtail  | −20 … +80 |

3-pin connector orientation on each channel column:

- **brown/black → GND** (outer-rim row, `–`)
- **red → V+** (middle)
- **orange/yellow → PWM** (signal, nearest the chip)

Reversing the connector is the #1 bring-up mistake — match the
silkscreen `GND/V+/PWM` rows exactly.

> When you wire all 6 legs later: **only joints 16 & 17 (leg 5 hip +
> knee) cross to board `0x41`.** Everything else is on `0x40`.

---

## 3b. The zero state — how the leg must sit at 0 / 0 / 0

`C` (and `J <j> 0`) drives every joint to **0°**. The servo horns must
be bolted on so that **0° corresponds to this pose**, or every angle you
command afterwards is off by the mounting error. Get this right *before*
you power the arm — it's also what makes the boot-time auto-centre safe.

**At 0 / 0 / 0 the whole leg is dead straight and horizontal, pointing
straight out from the body**, with coxa, femur, tibia, and foot all in
one line:

```
   zero state (side view, body at left):

   body | ==coxa== (Y)yaw  ==femur== (H)hip  ==tibia== (K)knee  ==> ● foot
                    axis ↕               axis ↺              axis ↺
        all three links colinear, parallel to the table, foot straight ahead
```

- **yaw = 0** → leg points straight out along its mounting azimuth (no
  fore/aft swing).
- **hip = 0** → femur is horizontal, in line with the coxa (not lifted).
- **knee = 0** → tibia is straight, in line with the femur (fully
  extended, no bend).

### Which way each axis moves (so you mount horns the right way round)

| Axis (joint) | `+` angle moves the link… | `−` angle moves it… | Range | Stance |
|---|---|---|---|---:|
| yaw (j0) | swings horizontally one way | the other way | ±35° | 0° |
| hip pitch (j1) | femur tip **down** | femur tip **up** | −80 … +30° | −25° |
| knee pitch (j2)| tibia tip **down** (folds under) | tibia tip **up** | −20 … +80° | +60° |

So the **standing stance (0, −25, +60)** is "femur lifted up ~25°, knee
folded down ~60°," which plants the foot below the body — the classic
knee-up / foot-down insect stance. Zero state is the *straightened-out*
version of that, which is easier to eyeball when mounting horns.

### Mounting each horn against zero

1. Send `C` so the PCA holds every channel at 0° (servo is now at its
   electrical centre, ~1500 µs).
2. With the servo powered and held at 0°, fit the horn/link so the link
   sits in the straight-out-horizontal zero pose above, then bolt it.
3. Don't fight the spline tooth pitch — get within one tooth, bolt it,
   then null out the rest with a software trim: `T <joint> <deg>`
   (clamped ±30°). e.g. if hip sits 4° high at "0", `T 1 -4`.
4. Re-send `C` and confirm all three links are straight and level.

> Trims are **saved to the Mega's EEPROM** and reloaded on every boot
> (before the initial centre), so you calibrate each joint **once** and
> it survives power-cycles and the serial-open auto-reset. You do not
> need to re-enter trims every time you power on.

> This is exactly why the boot-time `centreAll()` is safe **once horns
> are mounted at zero**: a reset just returns the leg to straight-out,
> not into a hard stop.

---

## 4. Bench bring-up sequence

**You drive the servos by typing commands into the Arduino IDE Serial
Monitor** — no Python, no Pi. The firmware parses newline-terminated
commands (see `prototype_servo_bridge.ino`):

| Type this | Does |
|---|---|
| `?` | print help |
| `C` | centre all joints (0°) |
| `J <joint> <deg>`| move one joint, e.g. `J 0 20` = joint 0 to +20° |
| `T <joint> <deg>`| set a trim offset (±30°), e.g. `T 1 -5` — **saved to EEPROM** |
| `P` | print the trim table |

Serial Monitor settings: **baud `115200`**, line ending **"Newline"**
(so each command is terminated with `\n`). Each command echoes `OK ...`.

> The firmware clamps every command to the safe per-axis limits (yaw
> ±35, hip −80…+30, knee −20…+80), so you can't drive past them even by
> typing a bigger number.

The Python client in `../pi_control/servo_bridge_client.py` is an
*optional* convenience (it adds smooth `--sweep` ramps and a `wiggle`
macro) — but it is **not needed** for any stage below.

> **Shortcut for Stages C–D:** flash
> `prototype_servo_test/prototype_servo_test.ino` instead of the bridge
> to **automatically march through every motor one at a time** and gently
> sweep each one. Open the Serial Monitor @ `115200` (line ending
> "Newline") and press **ENTER** to test the next joint (it prints which
> leg/axis/board/channel it's poking before it moves), `N 5` to test just
> joint 5, `L 0` to test all of leg 0, or `A` for the full 18-joint tour.
> It reuses the same safe per-axis limits and the EEPROM trims you set
> with the bridge's `T` command, so "0°" still matches your mounted horns.
> Re-flash `prototype_servo_bridge.ino` when you're done testing.

### Stage A — Rails only, nothing else connected
Bench supply set to **5.5 V, current limit 2.0 A**. No PCA, no Mega.

- [ ] Output reads ~5.5 V on the meter.
- [ ] No short between the V+ and GND leads (continuity = open).
- [ ] Supply OFF.

### Stage B — Mega + PCA9685 logic, no servos, no servo rail
Mega powered by **USB only** (laptop); bench supply still
OFF/disconnected. Just the Mega and PCA `0x40` — no Pi.

- [ ] Upload the **I²C scanner sketch** (§2); serial monitor @ `115200`
      lists `0x40` (and `0x41` if that board is wired + jumpered). If a
      board is missing, fix wiring / the `A0` jumper now.
- [ ] Re-flash `prototype_servo_bridge.ino` (needs the
      "Adafruit PWM Servo Driver Library").
- [ ] Serial @ `115200` prints `OK prototype_servo_bridge` + help.
- [ ] PCA + Mega regulators stay cool after a minute.

### Stage C — One spare servo, off the arm
Plug a **spare** DS3225 into `0x40` ch 0. Connect bench supply to the
PCA V+ terminal. Supply ON (still 5.5 V / 2 A limit). In the Serial
Monitor, type these one line at a time:

```
C            ← centre (joint 0 → 0°)
J 0 15       ← nudge +15°
J 0 0
J 0 -15      ← nudge −15°
J 0 0
J 0 30
J 0 -30
J 0 0
```

- [ ] Centres without a violent jump; each step is smooth both ways.
- [ ] Idle current is small; moving current well under 2 A (the supply
      shouldn't be hitting its limit / going into CV→CC).
- [ ] No continuous buzz (= stall), no overheating.

### Stage D — Leg 0 servos, one joint at a time
Plug the arm's 3 servos into `0x40` ch 0/1/2. **Clamp the arm, foot in
the air.** Raise the current limit to **~3 A** (three DS3225s).

> ⚠ On serial-open the Mega resets and `setup()` calls `centreAll()` →
> every joint jumps to 0°. Confirm each horn's 0° is near mid-travel
> *before* opening the Serial Monitor, or the arm can drive into a hard
> stop the instant you connect.

Step each joint out in small increments, typing one line at a time and
watching the joint after every step:

```
J 0 10       ← yaw toward +; then 20, then -20 (limit ±35)
J 1 -10      ← hip; then -25 (the stance value); stay within −80…+30
J 2 30       ← knee; then 60 (stance value); stay within −20…+80
```

- [ ] Each joint moves the **expected direction**.
- [ ] No mechanical binding before the firmware limit.
- [ ] Fix offsets with trim instead of re-bolting the horn, e.g. `T 1 -5`
      (trim is clamped ±30° and re-applies immediately).

### Stage E — Coordinated stance + load
Bring all three joints to the neutral standing pose by typing them in
sequence:

```
J 0 0
J 1 -25
J 2 60
```

- [ ] The leg settles into a stable stance pose.
- [ ] Hold 30–60 s: servos warm at most, supply not pinned at its limit.
- [ ] Let the foot lightly touch; small hip/knee moves feel sane.

> Optional: the `stance` command in the Python client sends all 18
> joints at once, but typing the three `J` lines above does the same
> thing for leg 0 with just the Serial Monitor.

### Stage F — IMU (requires the Pi, separate from the arm test)
The MPU-6050 is **not** on the Mega's bus. It's **4 wires** from the
GY-521 breakout straight to pins on the **Raspberry Pi's 40-pin
header**. Nothing here touches the Arduino.

**Wire each GY-521 pin to the Pi header pin in the same row:**

| GY-521 pin | → Pi header pin | What it is |
|---|---|---|
| `VCC` | **pin 1** (3V3 power) | power — use 3V3, **not** 5V (see warning) |
| `GND` | **pin 6** (Ground) | ground |
| `SCL` | **pin 5** (GPIO3 / SCL1) | I²C clock |
| `SDA` | **pin 3** (GPIO2 / SDA1) | I²C data |
| `AD0` | leave unconnected | sets address `0x68` |
| `XDA`,`XCL`,`INT` | leave unconnected | not used |

(Pi 40-pin header numbering: pin 1 is the corner nearest the SD-card /
board edge; odd pins are one row, even pins the other. Pins 1-3-5-6 are
all clustered at that same corner.)

> ⚠ **Power the GY-521 from 3V3 (pin 1), never 5V.** The breakout's
> SDA/SCL pull-up resistors go to whatever you feed `VCC`. On 5V they
> would pull the Pi's 3.3V I²C lines up to 5V and can damage the Pi.
> 3V3 keeps the bus at a safe 3.3V.

Then enable + scan I²C **on the Pi**:

```bash
sudo raspi-config        # Interface Options → I2C → Enable (once)
sudo apt install -y i2c-tools
i2cdetect -y 1           # expect 0x68
```

- [ ] `i2cdetect -y 1` on the Pi shows `0x68`.
- [ ] Read the MPU-6050 in Python; gyro/accel values change as you tilt
      the chassis.

---

## 5. Switching from bench supply to LiPo

Only after Stages A–F pass:

1. Bench supply OFF and disconnected.
2. Wire: `LiPo XT60 → anti-spark switch → split → BEC #1 (→ PCA 0x40)`
   and `BEC #2 (→ PCA 0x41)`.
3. **Set both BEC outputs to the same voltage (5.0–6.0 V) with the
   meter before connecting them to the PCAs.**
4. Re-verify common ground across LiPo −, both BECs, both PCAs, and the
   Mega. (The IMU shares ground with the Pi on its own bus.)
5. The **anti-spark switch is now your e-stop** — keep a hand near it
   for the first powered run.

Per the harness plan, **leg 0 needs no extension cables** — stock
pigtails reach ch 0/1/2 directly. Don't add slack you'll have to manage.

---

## Per-joint log (fill in for all 6 legs)

| Joint | Ch | Board | Neutral | Safe min | Safe max | Dir | Binds at | Notes |
|---:|---:|---|---:|---:|---:|-----|---|---|
| 0 yaw | 0  | 0x40  | 0 | | | | | |
| 1 hip | 1  | 0x40  | −25 | | | | | |
| 2 knee| 2  | 0x40  | +60 | | | | | |

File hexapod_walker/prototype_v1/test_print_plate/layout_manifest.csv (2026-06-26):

part | copy | x_mm | y_mm | rotate_z_deg
tibia_link.stl | 1 | -30.3 | -93.2 | 0
femur_link.stl | 1 | 84.0 | -61.0 | 90
coxa_link.stl | 1 | -84.5 | -44.8 | 0

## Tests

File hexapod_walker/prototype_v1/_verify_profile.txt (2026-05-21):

Cumulative-time cProfile snapshot of the FULL verifier suite (--serial
mode, captured 2026-05-21 on origin/main = 3e9082d "mixed-mode cradle
bolts").

Generation command:

    .venv/bin/python -m cProfile -o /tmp/verify.prof \
        hexapod_walker/prototype/_verify_prototype.py --serial
    .venv/bin/python -c "import pstats; \
        pstats.Stats('/tmp/verify.prof').sort_stats('cumulative').print_stats(40)" \
        > hexapod_walker/prototype/_verify_profile.txt

Why --serial?  cProfile only tracks the parent process; --serial moves
EVERY check (including the 175-pose workspace sweep) into the parent so
the snapshot is complete.  In the default pool-mode the same workload
walls in at ~ 95-150 s on this 8-core machine instead of ~ 810 s; the
~ 5 x speedup comes from the ProcessPoolExecutor fan-out, not from any
algorithmic change.  Use this snapshot to decide WHICH check / helper
to attack next, not to chase pool-mode wall-time bugs.

Top cumulative-time observations (driving the --fast and cache
follow-up commits):

  * 6-axis ray-vote point-in-mesh helper ``_points_inside_rays`` (called
    from ``points_inside``) dominates -- 747 s of 810 s, 92 % of the
    suite.  It is in turn dominated by trimesh's rtree-backed ray /
    triangle intersection (450 s, 56 %).  Nothing in --fast hits this
    path on the 175-pose sweep, which is why --fast lands at ~ 12 s.
  * ``check_workspace_self_collision`` is 659 s on its own (81 %) --
    175 poses x ~ 30 pair overlaps x ~ 100 ms / pair_overlap call.
  * ``check_flimsy_joints`` + ``check_horn_sweep_clearance`` add
    another ~ 90 s combined; both voxelise a multi-mm-pitch grid over
    the full femur / tibia bounding boxes.
  * ``check_servo_clearance``, ``check_cradle_insert_pockets``, and
    ``check_coxa_link_bridge_yz_thickness`` are each in the 15-25 s
    bucket -- the long tail.

------------------------------------------------------------------------

Thu May 21 15:05:50 2026    /tmp/verify.prof

         587069152 function calls (587024917 primitive calls) in 810.457 seconds

   Ordered by: cumulative time
   List reduced from 4952 to 40 due to restriction <40>

   ncalls  tottime  percall  cumtime  percall filename:lineno(function)
   1171/1    0.020    0.000  810.461  810.461 {built-in method builtins.exec}
        1    0.000    0.000  810.461  810.461 hexapod_walker/prototype/_verify_prototype.py:1(<module>)
        1    0.000    0.000  806.193  806.193 hexapod_walker/prototype/_verify_prototype.py:5036(main)
     9050    0.253    0.000  764.252    0.084 .venv/lib/python3.11/site-packages/trimesh/ray/ray_triangle.py:70(intersects_location)
     9050    3.441    0.000  763.999    0.084 .venv/lib/python3.11/site-packages/trimesh/ray/ray_triangle.py:23(intersects_id)
     1489    0.123    0.000  747.729    0.502 hexapod_walker/prototype/_verify_prototype.py:509(points_inside)
     1489    1.186    0.001  747.606    0.502 hexapod_walker/prototype/_verify_prototype.py:391(_points_inside_rays)
     9050   23.526    0.003  744.423    0.082 .venv/lib/python3.11/site-packages/trimesh/ray/ray_triangle.py:177(ray_triangle_id)
     9050   52.518    0.006  673.072    0.074 .venv/lib/python3.11/site-packages/trimesh/ray/ray_triangle.py:303(ray_triangle_candidates)
        1    0.000    0.000  659.133  659.133 hexapod_walker/prototype/_verify_prototype.py:2749(check_workspace_self_collision)
        1    0.000    0.000  659.126  659.126 hexapod_walker/prototype/_verify_prototype.py:2813(<listcomp>)
      176    0.051    0.000  659.126    3.745 hexapod_walker/prototype/_verify_prototype.py:2681(_workspace_pose_failures)
     3696    0.073    0.000  658.022    0.178 hexapod_walker/prototype/_verify_prototype.py:2448(_pair_overlap_volume_and_centroid)
 22027650  367.033    0.000  450.700    0.000 .venv/lib/python3.11/site-packages/rtree/index.py:755(intersection)
        1    0.001    0.001  146.472  146.472 hexapod_walker/prototype/_verify_prototype.py:4998(_run_checks_serial)
181023459   72.912    0.000  132.663    0.000 .venv/lib/python3.11/site-packages/rtree/index.py:935(_get_ids)
       52    0.007    0.000   85.873    1.651 hexapod_walker/prototype/_verify_prototype.py:1108(_pair_overlap_volume)
 22027650   52.912    0.000   58.184    0.000 .venv/lib/python3.11/site-packages/rtree/index.py:351(get_coordinate_pointers)
 44110269   55.418    0.000   55.484    0.000 ctypes/__init__.py:511(cast)
   124/72    0.106    0.001   55.432    0.770 .venv/lib/python3.11/site-packages/trimesh/constants.py:149(timed)
        1    0.007    0.007   54.555   54.555 hexapod_walker/prototype/_verify_prototype.py:2056(check_flimsy_joints)
        1    0.000    0.000   37.703   37.703 hexapod_walker/prototype/_verify_prototype.py:1486(check_horn_sweep_clearance)
       20    0.000    0.000   37.266    1.863 .venv/lib/python3.11/site-packages/trimesh/util.py:2346(__call__)
       10    0.000    0.000   37.219    3.722 .venv/lib/python3.11/site-packages/trimesh/base.py:2664(voxelized)
       10    0.000    0.000   37.219    3.722 .venv/lib/python3.11/site-packages/trimesh/voxel/creation.py:287(voxelize)
       10    0.306    0.031   37.120    3.712 .venv/lib/python3.11/site-packages/trimesh/voxel/creation.py:11(voxelize_subdivide)
        9    0.020    0.002   36.302    4.034 hexapod_walker/prototype/_verify_prototype.py:1642(_flimsy_clusters_for_part)
       10    9.852    0.985   31.689    3.169 .venv/lib/python3.11/site-packages/trimesh/remesh.py:117(subdivide_to_size)
     7926   10.303    0.001   31.059    0.004 .venv/lib/python3.11/site-packages/trimesh/triangles.py:504(points_to_barycentric)
        1    0.001    0.001   23.014   23.014 hexapod_walker/prototype/_verify_prototype.py:1247(check_servo_clearance)
     9050    4.565    0.001   21.299    0.002 .venv/lib/python3.11/site-packages/trimesh/ray/ray_triangle.py:340(ray_bounds)
     7926    3.587    0.000   20.723    0.003 .venv/lib/python3.11/site-packages/trimesh/triangles.py:543(method_cramer)
     7862    0.267    0.000   19.723    0.003 .venv/lib/python3.11/site-packages/trimesh/grouping.py:458(unique_rows)
    65656   19.339    0.000   19.370    0.000 .venv/lib/python3.11/site-packages/trimesh/util.py:539(diagonal_dot)
        1    0.001    0.001   18.170   18.170 hexapod_walker/prototype/_verify_prototype.py:1883(_check_coxa_link_bridge_yz_thickness)
       52    0.000    0.000   18.167    0.349 .venv/lib/python3.11/site-packages/trimesh/base.py:3148(contains)
       52    0.000    0.000   18.167    0.349 .venv/lib/python3.11/site-packages/trimesh/ray/ray_triangle.py:156(contains_points)
   104/52    0.032    0.000   18.160    0.349 .venv/lib/python3.11/site-packages/trimesh/ray/ray_util.py:7(contains_points)
     7901    0.372    0.000   16.820    0.002 .venv/lib/python3.11/site-packages/numpy/lib/_arraysetops_impl.py:145(unique)
     7901    2.071    0.000   16.438    0.002 .venv/lib/python3.11/site-packages/numpy/lib/_arraysetops_impl.py:350(_unique1d)

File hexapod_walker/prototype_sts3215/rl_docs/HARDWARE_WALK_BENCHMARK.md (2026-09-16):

# Hardware walking benchmark, version 1

The first recovery experiment is one forward three-second command window using
the already tested `hardware-walk-noyaw-v2-canary`, at its trained 0.08 m/s with
zero yaw. It uses the existing drive path, STEP walk-ready acquisition, and
planned STEP lower. It is a timing canary. The existing runner includes arming
in the command window and permits only 3–20 seconds; this specification does
not queue or authorize a 60-second run.

Generate reviewable Robot Lab payloads from the current source tree:

```sh
uv run python -m rl_move.scripts.hardware_walk_benchmark plan --output /tmp/hardware-walk-plan.json
```

By default the JSON `queue_payloads` list contains only the timing canary and
requires no optional sysid protocol files. Add `--include-planted` to also
generate the six separate supported planted comparisons, L5 through L0, when
that complete protocol set is installed and reviewed. Each item matches Robot Lab's
experiment creation fields and requires `execution_mode=external_guarded`.
Queueing leaves it `waiting_for_operator`; that legacy status means waiting for
the serialized guarded runner, not waiting for a person. This program has no
network or motion code. The guarded supervisor verifies every listed
prerequisite before starting one job; a fresh camera plus three advancing,
healthy 18/18 telemetry samples is sufficient when it conclusively establishes
normal state. Hands-on help is needed only for a persistent or inconclusive
physical condition. Resolve the current robot address and camera identity at
execution; the command placeholders deliberately contain no stale IP address.

The canary records the known checkpoint/export hashes, observation and motor
contract, and controller source hashes for interpreting results. Record the actual
versions used; a reviewed source change is not itself a reason to block an experiment.
Tag-layout calibration, additional timing reports, and long-duration acceptance
are not prerequisites for a walking comparison. Missing measurements limit what
we can conclude from a run, rather than making the run worthless.
Use a validated direct camera with source capture timestamps. The legacy HTTP
JPEG endpoint does not prove frame freshness from receipt time alone and is not
the camera source for this plan.

The planted jobs reuse the exact versioned 174-second radial-shear protocols.
Generation checks that only the selected hip/knee targets vary across home
acquisition and every segment boundary, rejects unaudited segment types, and records the
file SHA-256. L4 uses version 2, without the older adjacent-leg yaw movement.
These are supported characterization jobs, not walking or repair acceptance.
`sysid.run_hw` alone does not enforce all support/camera gates: the serialized guarded
supervisor must do so. Coordinated hip/knee current trips do not use the
single-joint automatic current-retry exception. The canonical stop rules remain
in `EMERGENCY_HANDLING.md` (lukas/hexapod-orchestrator).

Audit saved recordings without contacting the robot:

```sh
uv run python -m rl_move.scripts.hardware_walk_benchmark analyze \
  rl_move/hardware_traces/rl_walk_trial_20260904_232355 \
  --output /tmp/hardware-walk-baseline.json
```

The report separates requested command duration, host command wall window,
scheduled policy `t_s`, and actual continuous engaged wall time. Only advancing
per-tick `mono_s`, `wall_elapsed_s`, or `unix_s` plus explicit `walk_engaged` or
`learned_policy_active` can establish actual engagement. The sampled span is a
lower bound; no final tick is extrapolated. Interrupted engagement (including
hold rows between walking segments) or logging gaps over 250 ms cannot establish
continuity. Split interrupted runs before scoring. Legacy traces remain useful for service/write
time, overruns, attitude and repeated feedback, but their nominal clock never
proves actual cadence or active duration. Repeated joint values may mean cached
feedback or stillness; they are not an independent sensor-age or stall measure.

New episode logging should provide `mono_s`, `walk_engaged`, `state_age_ms`,
`position_age_ms`, `imu_age_ms`, and `bus_write_due`. Missing fields remain null
or empty statistics; they never become zero error. Summary current/tilt maxima
remain explicitly recorded values and require normal telemetry/video review.

Metric progress requires a separately validated floor-pose measurement. Put
`calibrated_motion.json` (or `calibrated_motion_forward.json`, etc.) beside a
saved trial, using this schema. The trace hash binds it to that exact episode;
times must share the engagement clock and cover its entire interval.

```json
{
  "schema": "hexapod.calibrated_motion.v1",
  "calibration_status": "validated",
  "calibration_id": "the-real-calibration-record-id",
  "frame": "floor",
  "units": "m",
  "trace_sha256": "SHA256_OF_THE_RAW_EPISODE_CSV",
  "clock": "mono_s",
  "samples": [
    {"t": 100.0, "x": 0.0, "y": 0.0, "yaw_deg": 0.0},
    {"t": 102.0, "x": 0.04, "y": 0.01, "yaw_deg": 1.0}
  ]
}
```

These numbers illustrate the file format, not a hardware result. Calibrated
output requires an explicitly selected, content-addressed Robot Lab calibration
archive whose request, report, pose configuration, and historical layout hashes
match the supplied replay snapshots. Robot Lab intentionally leaves archival
records `current:false` and `replay_ready:false`; explicit offline selection is
not activation. Motion is projected onto the initial body heading plus the
constant commanded direction; course error is the angle of net displacement,
and yaw change is reported separately. A
direction-changing course needs per-segment analysis and is not scored by this
constant-direction calculation. Video alone does not supply metric distance.

The future duration criterion is three distinct, continuous 60-second trials,
each with actual engagement timestamps, no recorded fall, and calibrated motion.
Three short clips cannot be concatenated, and one folder or duplicate raw trace
cannot count as three repeats. Even that criterion is only duration/pose
evidence: smoothness, foot clearance/slip, course control, current/thermal
behavior, reliable start/stop and the chosen acceptance thresholds still require
review. This fixed-speed no-yaw policy cannot demonstrate steering or
variable-speed competence.

The runner accepts `--walk-transport drive --velocity-filter-alpha 0.8`;
use `0.3` for a matched baseline. The robot drive API accepts
`velocity_filter_alpha` on `/api/rl/drive/start`. The override lasts only for
that session and the actual value is recorded in the episode result; omission
preserves `rl_move/config.yaml`. Keep the policy, gait, speed, transport and
observation cadence fixed within a comparison. The original alpha comparison
was proposed for the historical 100/50/10 Hz transport; it does not establish
the best filter for the restored 100 Hz path. Record the actual controller
and cadence, then judge repeated physical walks under matched floor and
starting-pose conditions.

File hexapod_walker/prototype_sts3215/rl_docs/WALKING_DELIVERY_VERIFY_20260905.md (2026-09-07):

# Walking delivery verification — 2026-09-05 (orchestrator, controller pod)

Executes operator feedback `fb_20260905T075426_969b3d` ("keep 100 Hz and
isolate filter lag") against the published `codex/smooth-walking-delivery`
branch (tip `c3f3ddb4`), in an isolated worktree. CPU only; zero PPO; no
physical robot access; the policy stays 100 Hz throughout. The Codex-owned
runtime/exporter files were not edited; main's campaign source is untouched.

## 1. Copied actor and model/motor hash verification

- **Actor bytes are NOT verifiable from this pod.** The frozen actor
  (`hardware-walk-noyaw-v2-canary`) lives in the operator checkout's
  untracked `artifacts/rl_policy_hardware/...`; it is not in the repo, the
  run ledger, or the W&B project. What IS verifiable: `actor_sha256`
  (`58a9bbf7…`) and `checkpoint_sha256` (`250643a4…`) are **bit-identical
  across all six replay reports and the checked-in Robot Lab timing canary
  plan** — internally consistent provenance, single frozen actor everywhere.
- **Motor model MATCHES:** `rl_move/sim/sim_model.json` sha256 `6968268e…`
  matches this repo bit-exactly in every report row.
- **Sim model MISMATCH (honest flag):** all replay rows ran on a
  **4.80573 kg full-mesh model** (`hexapod_mesh.xml` sha `7efb8e8a…`)
  generated in the operator's checkout. This repo cannot regenerate it:
  a fresh `build_mesh_model.py` build here gives **3.490 kg**
  (sha `dd6275c0…`; the campaign's audited as-built mass is 3.50 kg), with
  **19/34 referenced meshes byte-different** (coxa/femur/tibia links,
  servos, chassis, bearings). The published absolute progress/slip numbers
  are therefore tied to a model ~37 % heavier than the audited as-built
  robot; the branch doc itself flags this. Which CAD state produced 4.8 kg
  needs a Codex-side answer (their checkout at
  `/Users/lukas/Documents/ChatGPT/hexapod project`).
- Side observation: a fresh mesh build also rewrites the TRACKED
  `hexapod_mesh_mjx.xml` twin (current CAD, incl. the 09-04 leg-geometry/
  boot update, no longer reproduces the committed twin bit-exactly). Both
  checkouts were restored to the committed twin; no training default was
  changed. Worth a deliberate refresh decision later — separate question.

## 2. Faster-filter comparison — independent reproduction

Since the exact actor is unavailable here, the comparison was reproduced
with a DIFFERENT frozen 100 Hz actor under the identical harness: the
todaypolicy bundle walk role
(`cw-walk-allheading-mlp-singleframe-acq1-stdanneal`, obs 74 / hidden
128×128 / robot_abs_tibia_v2 / walk_obs_body_vel=2 / 0.08 m/s — same
contract family as the canary), exported via `export_policy_np` (parity
1.4e-07), on this repo's regenerated 3.490 kg full mesh. Same seed,
10 s, DR-0, forward + sideways. Artifacts:
`logs/ckpt_eval/deployed_transport_substitute_20260905*`.

| Policy 100 Hz, write/feedback | fwd prog (op / here) | side prog (op / here) |
|---|---|---|
| nominal | .433 / .426 | .379 / .360 |
| 50 / 10 (orig filters) | .294 / .269 | .297 / .230 |
| 50 / 50 (orig alphas) | .368 / .350 | .359 / .324 |
| 50 / 50, matched slow bandwidth | .296 / .335 | .280 / .236 |
| 50 / 10, faster filters | .366 / .340 | .327 / .266 |
| 100 / 100 | .414 / .422 | .369 / .361 |

Filter-alpha arithmetic verified exact: fast = 1−0.7⁵ / 0.98⁵; matched
slow bandwidth = 1−0.7^(1/5) / 0.98^(1/5).

**Reproduced on a different actor and different-mass model:** the deployed
transport costs real progress; faster filters at the existing 10 Hz
feedback recover ~88 % of the forward 50 Hz-sensing gain (op: ~100 %);
sideways recovers only ~38 % (op: ~48 %) — sideways genuinely wants
cadence, matching the branch doc. **One honest divergence:** the
matched-slow-bandwidth control removes essentially all of the sideways
gain here (as published) but only ~19 % of the forward gain (op: ~all) —
for this actor a real fraction of the forward 50 Hz gain is cadence, not
filter lag. The "filter lag is a major, separable component" conclusion
stands; its forward-share is actor-dependent.

## 3. Matched noise-sensitivity screen (new, opt-in tooling)

`eval_deployed_transport.py` gained `--sensor-noise-json`
(`NoisySensorTransport`): seeded fixed-block noise injected on the RAW
frame at the transport acquisition hook (encoder/gyro/accel-tilt, before
the hardware filters), bit-identical draws across filter arms, identity at
zero scales; 3 new unit tests (19/19 file green; envelope bank 13/13).
Deployed-only cells (the nominal path has no acquisition hook). Scales =
campaign DR floors: encoder 0.09°, gyro 0.5°/s, tilt 0.3°.

| arm (w50) | clean fwd/side | 1× floor | 2× floor |
|---|---|---|---|
| s10 orig filters | .269 / .230 | .292 / .236 | .294 / .292 |
| s10 **fast filters** | .340 / .266 | .324 / .249 | .280 / .256 |
| s50 orig alphas | .350 / .324 | .333 / .263 | — |

At 1× DR-floor noise the fast-filter candidate keeps most of its clean-sim
forward advantage (.324 vs .292, slip 3.82 vs 4.23). At 2× floor the
advantage is gone forward (.280 vs .294, slip 4.59 vs 4.07). Single
deterministic 10 s cells — a screen, not a gate; treat ±0.03 as noise.
**Consequence:** the faster filters are usable-looking at nominal noise but
their margin dies within 2× — the branch's "first inspect estimator
response against recorded encoder/IMU data" order is the right gate before
any deployment decision. No deployment recommendation is made here.

## 4. Stop/restart slip measurement — corrected and re-run

The worktree's corrected evaluator
(`slip_metric_version=commanded_intervals_v2_stop_history_advanced`)
was re-run on the **exact published model** (08-30 mesh, verified by
bit-identical progress vs `command_envelope_v1_09-05/summary.json`),
scenario `stop_restart`, seed 0 (published seed 0/1 rows were identical):
`logs/ckpt_eval/command_envelope_stoprestart_slipv2_09-05/`.

| arm | published slip/ach-m (v1, biased) | corrected (v2) |
|---|---|---|
| baseline | 1.384 | **1.314** |
| env_shared / env_yawpri | 1.559 | **1.365** |

The old metric charged paused-interval foot drift to the restart: the
envelope's apparent +12.6 % stop/restart slip penalty vs baseline is
mostly artifact; the real penalty is **+3.9 %** (ramp cost, direction
unchanged). Progress/yaw conclusions were never affected. Other published
scenarios have no mid-episode zero-command segment, so their slip values
are unaffected; the timeslice table on main (combo scenarios) is likewise
unaffected by this specific bug.

## 5. Regression check on the branch's default path

With the transport disabled and the same model files, branch code
reproduces main's published rollout **bit-exactly**
(prog 0.41362140257794966) — no default-behavior regression found in
`sim_env.py`/`safety.py`/`robot_state.py` for this path. An initial
4e-4 progress drift was traced to the fresh mesh regen (CAD moved on
09-04), not to code.

## Assumptions and limits

- Substitute-actor reproduction tests the TRANSPORT mechanism, not the
  canary actor's exact numbers; per-cell values differ from the published
  ones and should not be merged into one table without these labels.
- One seed, two headings, 10 s, DR-0 throughout: diagnostic screens.
- Noise scales are sim DR floors, not measured hardware noise; the
  injector cannot noise the nominal path.
- Simulated current remains an uncalibrated proxy; no freshness-stop/
  readiness replay (branch limitation list still applies).

## Next measurable step

Codex-owned, per the branch doc order: fit the estimator/filter response
against RECORDED hardware encoder/IMU traces (they exist under
`rl_move/hardware_traces/`), extract the real sensor-noise floor, then
re-run this matched screen at the MEASURED noise level — that single
number decides whether the fast-filter candidate survives. On this side,
nothing further is runnable until that measured floor exists; the
`env_yawpri` and time-slice rulings on main are unchanged.

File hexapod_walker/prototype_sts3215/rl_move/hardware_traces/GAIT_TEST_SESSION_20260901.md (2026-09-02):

# Scripted-gait sim-to-real session — 2026-09-01

## Final robot state

- Collision-aware STEP-lower recovery completed after five consecutive cool
  readings and explicit operator authorization.
- Post-recovery verification: 18/18 live, maximum absolute encoder error
  0.26 degrees, 34 C maximum, then `X` limp.
- Deployed watchdog reports `temp_trip_reads: 3`.
- After the rotated repeats: 18/18 live, maximum absolute zero error 0.26
  degrees, 35 C maximum, and limp/disarmed.

## Gait 10 vs gait 0 — three complete paired surveys

All three surveys completed without recovery or safety trip:

- `scripted_gait_suite_20260901_114217`
- `scripted_gait_suite_20260901_115050`
- `scripted_gait_suite_20260901_115532`

At a 30 mm/s command, AprilTag floor-projected chassis speed was:

| Direction | Gait 0 median | Gait 10 median | Paired gait-10 / gait-0 |
|---|---:|---:|---:|
| Forward | 14.853 mm/s | 10.973 mm/s | 0.744 median |
| Backward | 8.327 mm/s | 16.726 mm/s | 1.921 median |
| Two-direction mean | — | — | 1.166 median, 1.178 mean |

Conclusion: gait 10 transfers as a strong robot-local reverse gait, but is
not a general forward-speed improvement. The paired average improvement was
13.2–23.6% across the three runs. The direction dependence is too large to
attribute to random camera noise.

Aggregate: `gait_reliability_20260901_gait0_vs_gait10.json`.

## Gait 9 exploration

The first complete paired run, `scripted_gait_suite_20260901_120420`, measured:

| Direction | Gait 0 | Gait 9 | Paired gait-9 / gait-0 |
|---|---:|---:|---:|
| Forward | 18.483 mm/s | 16.669 mm/s | 0.902 |
| Backward | 10.235 mm/s | 18.682 mm/s | 1.825 |
| Two-direction mean | 14.359 mm/s | 17.676 mm/s | 1.231 |

Gait 9 is the best candidate for the next session: its first real run retained
most baseline forward speed while producing the same large reverse gain. It is
not yet reliable evidence because only one complete trial exists.

The second attempt, `scripted_gait_suite_20260901_120655`, stopped before gait
9 completed. Joint 1 temperature changed 32 -> 83 -> 102 C in 0.67 seconds and
returned to 31–34 C afterward. This is thermally impossible and consistent
with corrupt bulk-feedback bytes, but it satisfied the old two-read cutoff.
The partial speeds remain in the artifact directory and are excluded from the
aggregate because its manifest status is `failed`.

Aggregate: `gait_reliability_20260901_gait0_vs_gait9.json`.

## Gait 9 after a physical 180-degree rotation

The robot was turned approximately 180 degrees while the camera and all floor
tags stayed fixed, then manually repositioned toward the middle of the camera.
Three complete paired six-second surveys were recorded:

- `scripted_gait_suite_20260901_124147`
- `scripted_gait_suite_20260901_124426`
- `scripted_gait_suite_20260901_124810`

| Direction | Gait 0 median | Gait 9 median | Paired gait-9 / gait-0 |
|---|---:|---:|---:|
| Forward | 16.181 mm/s | 15.129 mm/s | 0.928 median |
| Backward | 7.000 mm/s | 15.512 mm/s | 2.216 median |
| Two-direction mean | — | — | 1.454 median, 1.421 mean |

Gait 9 backward was especially repeatable: 15.04--15.65 mm/s, CV 0.021.
Across the original complete run plus the three rotated runs, gait 9 measured
15.899 mm/s forward and 15.579 mm/s backward by median. Its median paired
two-direction improvement over gait 0 was 36.8%, with all four complete runs
positive (23.1--52.6%).

The basic gait remained robot-local forward-biased after rotation: its
four-run medians were 16.535 mm/s forward and 7.956 mm/s backward. Therefore
the garage grade is not the dominant explanation for the asymmetry. It may
still account for a smaller absolute-speed shift.

Aggregates:

- `gait_reliability_20260901_rotated_gait0_vs_gait9.json`
- `gait_reliability_20260901_gait0_vs_gait9_all_complete.json`

## Recovery and infrastructure findings during the rotated test

- `scripted_gait_suite_20260901_123228` retained its recordings after two
  identical -179.87-degree IMU Euler samples caused a false tilt stop. The
  robot was visibly upright and immediately returned to about -3 degrees.
  Tilt now requires three valid samples, and a discontinuous near-180-degree
  jump with a quiet gyro is logged but cannot accumulate stop votes.
- Explicit collision-aware zero recovery completed from the interrupted gait
  pose after five stable health readings; zero error was at most 0.53 degrees.
- `scripted_gait_suite_20260901_123747` stopped when the chassis was 0.29 m
  from its anchor, beyond the centering controller's 0.25 m trusted range. The
  ordinary-failure recovery correctly lowered to zero and limped. The partial
  run is excluded from reliability aggregation.
- Continuity Camera sometimes fails to reacquire its native 420v stream after
  a recorder subprocess exits. Restarting only the local Mac `:8898` service
  restores it; the robot remains zero and limp during that restart.
- `/api/measure/walk` could previously mark a disarmed zero pose as a stand
  without physically acquiring walk-ready. It now always runs validated
  zero-to-stand acquisition when disarmed.
- The completed rotated runs contained isolated impossible temperature bytes
  as high as 68 C, but no joint produced three consecutive hot readings. The
  confirmed temperatures stayed at or below 38 C.

## Candidate-screen conclusion

A matched MuJoCo screen at 30 mm/s ranked gait 9 ahead of fluid variants
11--13. Gait 10 was faster than gait 9 in idealized MuJoCo (about 20.7 versus
18.7 mm/s), but its earlier hardware average was slower and strongly
directional. Raising gait 9's command to 40 mm/s did not increase simulated
speed because its fixed period/stride envelope was already saturated.

The next useful speed experiment is an intermediate fluid preset between gait
9 (2.9 s period, 18 mm lift) and gait 10 (2.4 s, 14 mm), followed by the same
three-run paired hardware protocol. The simulator objective must penalize
direction asymmetry and body motion; speed-only MuJoCo ranking currently
prefers gait 10 for the wrong reason.

## What the matched MuJoCo replay says

For the complete gait-9 run, MuJoCo predicted approximately 18.94 mm/s forward
and 19.50 mm/s backward for gait 9; hardware measured 16.67 and 18.68 mm/s.
That candidate transferred surprisingly well in absolute speed. Gait 0 did
not: simulation predicted 11.18/10.36 mm/s, while hardware measured
18.48/10.24 mm/s.

Joint trajectory RMSE was only about 2.1–2.6 degrees, so motor command tracking
is not the dominant mismatch. The larger residuals are contact/body dynamics:
hardware IMU peak tilt was roughly 7–15 degrees while MuJoCo rigid-body tilt
was only 0.3–0.5 degrees, and MuJoCo peak-current estimates were much larger
than measured servo currents. Do not compare the two tilt signals as an exact
residual, but their scale difference shows that the simulated chassis is much
more settled than the real robot.

## Original follow-up protocol (completed in this session)

1. Physically rotate the robot 180 degrees while leaving the camera and floor
   tags fixed; capture a new image anchor.
2. Collect three complete paired gait-0/gait-9 surveys at 30 mm/s. Do not raise
   speed until all three finish without recovery or safety trip.
3. If the fast physical direction stays fixed in the garage, fit floor grade
   and directional/anisotropic friction. If the advantage stays robot-local
   backward, focus on gait geometry, leg compliance, and mass asymmetry.
4. Fit MuJoCo against AprilTag progress, lateral drift, yaw, body tilt, and
   joint tracking together. Add plane tilt, friction spread/anisotropy, foot
   compliance, actuator lag/deadband, and per-leg asymmetry to domain
   randomization. Ranking on speed alone will overfit the current idealized
   contact model.

The stationary IMU reading during this session was typically about 1–3 degrees
from level, which is compatible with a modest garage grade but is not proof;
the 180-degree paired test is the discriminating experiment.

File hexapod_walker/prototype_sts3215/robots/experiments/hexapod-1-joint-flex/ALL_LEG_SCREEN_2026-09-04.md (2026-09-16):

# All-leg independent hysteresis screen

Campaign ID: `hexapod-1-all-leg-hysteresis-20260904`

## Question

Is L5 still an outlier when all six legs are tested in the same supported,
camera-observed session with the same radial-shear trajectories?

This is a descriptive hardware comparison, not a repair acceptance.  It uses
three within-run cycles per condition and reports L5 against the distribution
of the five peer legs.  A second block is run only if the first result is
ambiguous, interrupted, or contradicted by the camera evidence.

## Motion and camera scope

- The chassis remains rigidly supported for every job.
- Jobs are guarded-runner-started one at a time.  Robot Lab must show
  `waiting_for_operator`; its built-in simulated worker must not execute them.
- Only the selected leg's hip and knee command change during a trajectory.
  The other joint targets remain at the verified home pose.
- There is no autonomous whole-body turn.  After a job ends limp, the operator
  manually rotates the supported chassis to expose the next leg to the USB
  cameras, reseats the supports, and repeats every preflight gate.
- The complete air block must pass before any planted job is considered.

## Queue order

The air order runs around the body; the planted order reverses it to reduce
systematic time and temperature bias.

| Step | Profile | Leg | Protocol | Duration | Protocol hash |
|---:|---|---|---|---:|---|
| 1 | air | L0 | `l0_air_radial_shear_hysteresis_control_v1.json` | 78 s | `ba179b6004dc` |
| 2 | air | L1 | `l1_air_radial_shear_hysteresis_control_v1.json` | 78 s | `54e13e78078d` |
| 3 | air | L2 | `l2_air_radial_shear_hysteresis_control_v1.json` | 78 s | `0d527717ddee` |
| 4 | air | L3 | `l3_air_radial_shear_hysteresis_control_v1.json` | 78 s | `deafc345719f` |
| 5 | air | L4 | `l4_air_radial_shear_hysteresis_control_v2.json` | 78 s | `d80204caa013` |
| 6 | air | L5 | `l5_air_radial_shear_hysteresis_control_v1.json` | 78 s | `eacce87be616` |
| 7 | planted | L5 | `l5_ground_radial_shear_amplitude_ladder_v1.json` | 174 s | `c1cdf27da874` |
| 8 | planted | L4 | `l4_ground_radial_shear_amplitude_ladder_v2.json` | 174 s | `b8b2f4bf027e` |
| 9 | planted | L3 | `l3_ground_radial_shear_amplitude_ladder_v1.json` | 174 s | `1e2f65a90a91` |
| 10 | planted | L2 | `l2_ground_radial_shear_amplitude_ladder_v1.json` | 174 s | `a1cb453ad68b` |
| 11 | planted | L1 | `l1_ground_radial_shear_amplitude_ladder_v1.json` | 174 s | `b08cbbd244d5` |
| 12 | planted | L0 | `l0_ground_radial_shear_amplitude_ladder_v1.json` | 174 s | `dc61d4194c4c` |

The checked-in L4 v1 trajectories are not used: they yaw L3 and L5 for the
old camera placement.  The L4 v2 trajectories remove that camera-clearance
motion and assert that only L4 hip and knee vary.

## Required gate before every job

1. Confirm an operator is present and the physical e-stop/abort path is ready.
2. Confirm no robot/demo/sysid job is active.  Start from idle, disarmed, and
   limp; never preempt another job.
3. Confirm rigid supports are stable.  For the planted block, only the target
   foot receives the intended contact while the chassis support carries the
   robot.
4. Compare the physical pose with logical zero.  If they disagree, stop and
   perform the documented set-zero-here procedure before any absolute pose.
5. Require three fresh healthy samples: 18/18 servos, IMU healthy, normal
   electrical/current/temperature telemetry, and no persistent missing ID.
6. Verify both USB camera identities and live views after the manual rotation.
   The target hip/knee tag plus a body or floor reference must be visible; no
   support or camera may move during a trajectory.
7. Verify the protocol name and hash in this table.  The external supervisor
   must enforce these gates; `sysid.run_hw`'s built-in preflight alone is not
   sufficient.

## Stop and retry rules

Every completion, rejection, interrupt, or trip ends limp.  Stop without an
automatic retry for a tip, visibly bad posture, support movement, brownout,
hot motor, jam, surprise force, confirmed overcurrent, or camera evidence of
unsafe motion.  These trajectories coordinate hip and knee and hold all 18
targets, so the single-joint grounded-current auto-retry exception does not
apply.  Only a recoverable missing-feedback, camera, recorder, or framework
stop may retry: inspect the live cameras, require three fresh healthy samples,
and retry the complete leg job at most twice, following
`EMERGENCY_HANDLING.md` (lukas/hexapod-orchestrator).

## Evidence and comparison

Capture the hardware CSV, exact protocol JSON/hash, result summary, synchronized
camera sidecar, start/end telemetry, and current tag-layout revision for every
job.  Analyze each CSV with `sysid.analyze_hysteresis`, preserving both signed
midpoint differences and the mean absolute hip/knee loop per condition.

Report, for air and for each planted amplitude:

- all six hip and knee loop values;
- L5's ratio to the peer median and to the largest peer;
- cycle-to-cycle range and any invalid camera or telemetry interval; and
- whether the encoder direction and visible tag motion agree.

Treat L5 as a contemporaneous outlier only when its separation from every peer
is larger than the within-run scatter/noise and repeats coherently across the
relevant conditions.  The pre-registered practical gate is at least four
encoder counts (0.352 degrees), preferably also at least 2x the largest peer,
in air and in at least three planted amplitudes.  Do not turn the six-leg
screen into an automatic stand, gait, or repair-acceptance decision.

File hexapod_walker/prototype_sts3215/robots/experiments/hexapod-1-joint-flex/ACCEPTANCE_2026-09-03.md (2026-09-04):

# L5 supported acceptance retest — 2026-09-03

## Disposition

**L5 is not demonstrated repaired; the measured residual was explicitly
accepted by the operator for this campaign on 2026-09-03.** The supported air
control improved, but the planted ladder reproduced the previously abnormal
L5 hip/knee hysteresis. The robot returned limp at zero with all 18 servos
present and no visible support or geometry change. That acceptance cleared the
campaign's process gate for guarded whole-body gait and walk-only policy tests;
it does not erase or reclassify the hardware finding.

## Runs

| Test | Result | Control ticks | Camera samples | Peak current |
|---|---|---:|---:|---:|
| L5 air radial-shear control | clean completion | 780/780 | 759 | 0.039 A |
| L5 planted 3.75–15 mm ladder | clean completion | 1,740/1,740 | 1,660 | 0.0845 A |

Both protocols used soft torque 700, a three-consecutive-sample trip at
0.75 A, and an immediate 3.0 A ceiling. Neither run aborted or clamped a
command. The planted run had 12 catch-up overruns in one 0.15-second cluster
near 62.2 seconds; none fell in a measurement dwell window.

The final independent health check reported 18/18 servos, zero current,
11.2 V minimum, 32 °C maximum, no alarms, and at most 0.26 degrees from the
zero pose. The CSV temperature field contained intermittent impossible
single-sample values up to 132 °C. These conflict with the fresh per-servo
status scan before and after the run and are not treated as confirmed
temperatures; the telemetry decoder/freshness path needs correction before a
gait temperature claim relies on that field.

## Encoder hysteresis

Equal-command loop magnitude in the unloaded control was:

| Run | L5 hip | L5 knee |
|---|---:|---:|
| 2026-09-03 acceptance | 0.830° | 0.181° |
| previous 2026-09-03 repeat | 1.143° | 0.352° |
| previous L4 reference | 0.059° | 0.088° |

The knee improved substantially and the hip improved modestly, but the hip
loop remains about fourteen times the L4 reference.

The planted ladder measured:

| Radial command | L5 hip | L5 knee |
|---:|---:|---:|
| 3.75 mm | 0.776° | 0.688° |
| 7.5 mm | 1.045° | 0.835° |
| 11.25 mm | 1.271° | 1.085° |
| 15 mm | 1.091° | 0.967° |

This is materially unchanged from the previous L5 ranges of 0.645–1.259° hip
and 0.586–1.113° knee, and remains well above the prior L4 planted range of
0.088–0.351°.

## Vision and model-fit limits

The standalone camera server and guarded runner captured synchronized state
documents with zero HTTP capture errors and camera-1 JPEGs that were assembled
into MP4s. The existing camera joint estimator tracked L5 hip in 1,257/1,660
planted samples, but did not track L5 knee. The newly configured L5 component
tags 48, 58, 63, and 64 were not visible in any captured pose document from
the current camera geometry. Camera-derived L4/L5 compliance therefore cannot
be fit defensibly from this acceptance run.

Robot feedback exposed through the camera server also became stale while the
exclusive sysid trajectory owned the robot API, so its apparent IMU range is
not a synchronized body-tilt measurement. These two gaps must be fixed or the
robot/camera geometry changed before fitting per-leg visual compliance and body
tilt. Directional friction likewise requires the paused forward/backward gait
run.

## Gait-14 simulation screen

The proposed 2.65-second, 16 mm, continuous-timing gait passed the requested
MuJoCo joint-rate/workspace screen in both directions at 30 mm/s for 6 seconds:

| Direction | Travel/command | Joint rate p95 / max | Workspace fallbacks | Limit clips | Min limit margin | Max tilt |
|---|---:|---:|---:|---:|---:|---:|
| Forward | 0.118/0.140 m | 32.1/71.8°/s | 0 | 0 | 6.1° | 0.3° |
| Backward | 0.115/0.140 m | 31.5/71.8°/s | 0 | 0 | 6.1° | 0.3° |

The primitive-collision model still showed 264–269 mm of scrub, reinforcing
the known contact/body-dynamics reality gap rather than invalidating the
joint-rate/workspace screen.

Gait 14 was subsequently deployed with the documented helper after installing
a dedicated robot SSH identity. The first clean hardware pilot and two complete
paired repeats were recorded; the final repeat and policy walk remain in
progress at the time of this acceptance-note update.
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

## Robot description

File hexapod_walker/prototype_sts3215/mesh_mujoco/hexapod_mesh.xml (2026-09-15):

<mujoco model="hexapod_sts3215_mesh">
  <compiler angle="radian" coordinate="local" autolimits="true" meshdir="assets"/>
  <option gravity="0 0 -9.81" timestep="0.002" iterations="50" solver="Newton" cone="elliptic"/>
  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

  <default>
    <joint armature="0.0004" damping="0.01" limited="true"/>
    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
    <default class="part">
      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
    </default>
    <default class="legpart">
      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
    </default>
    <default class="visual">
      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
    </default>
    <default class="foot">
      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
    </default>
  </default>

  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

  <worldbody>
    <light name="sun" pos="2 -1.5 2.2" dir="-0.6 0.4 -1" castshadow="true"/>
    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

    <body name="chassis" pos="0 0 0.125420">
      <freejoint name="root"/>
      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

      <body name="L0_yaw" pos="0.086603 0.050000 0.015250" quat="0.96592583 0 0 0.25881905">
        <joint name="L0_yaw" type="hinge" axis="0 0 1" range="-0.61 0.61"/>
        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
        <body name="L0_femur" pos="0.012500 -0.025650 0.038400">
          <joint name="L0_pitch" type="hinge" axis="0 1 0" range="-1.4 0.52"/>
          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
          <body name="L0_tibia" pos="0.090000 0 0">
            <joint name="L0_knee" type="hinge" axis="0 1 0" range="-0.35 2.62"/>
            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
            <body name="L0_pad" pos="0.142000 0.024150 0.000000">
              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
            </body>
          </body>
        </body>
      </body>
      <body name="L1_yaw" pos="0.000000 0.100000 0.015250" quat="0.70710678 0 0 0.70710678">
        <joint name="L1_yaw" type="hinge" axis="0 0 1" range="-0.61 0.61"/>
        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
        <body name="L1_femur" pos="0.012500 -0.025650 0.038400">
          <joint name="L1_pitch" type="hinge" axis="0 1 0" range="-1.4 0.52"/>
          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
          <body name="L1_tibia" pos="0.090000 0 0">
            <joint name="L1_knee" type="hinge" axis="0 1 0" range="-0.35 2.62"/>
            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
            <body name="L1_pad" pos="0.142000 0.024150 0.000000">
              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
            </body>
          </body>
        </body>
      </body>
      <body name="L2_yaw" pos="-0.086603 0.050000 0.015250" quat="0.25881905 0 0 0.96592583">
        <joint name="L2_yaw" type="hinge" axis="0 0 1" range="-0.61 0.61"/>
        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
        <body name="L2_femur" pos="0.012500 -0.025650 0.038400">
          <joint name="L2_pitch" type="hinge" axis="0 1 0" range="-1.4 0.52"/>
          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
          <body name="L2_tibia" pos="0.090000 0 0">
            <joint name="L2_knee" type="hinge" axis="0 1 0" range="-0.35 2.62"/>
            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
            <body name="L2_pad" pos="0.142000 0.024150 0.000000">
              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
            </body>
          </body>
        </body>
      </body>
      <body name="L3_yaw" pos="-0.086603 -0.050000 0.015250" quat="-0.25881905 0 0 0.96592583">
        <joint name="L3_yaw" type="hinge" axis="0 0 1" range="-0.61 0.61"/>
        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
        <body name="L3_femur" pos="0.012500 -0.025650 0.038400">
          <joint name="L3_pitch" type="hinge" axis="0 1 0" range="-1.4 0.52"/>
          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
          <body name="L3_tibia" pos="0.090000 0 0">
            <joint name="L3_knee" type="hinge" axis="0 1 0" range="-0.35 2.62"/>
            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
            <body name="L3_pad" pos="0.142000 0.024150 0.000000">
              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
            </body>
          </body>
        </body>
      </body>
      <body name="L4_yaw" pos="-0.000000 -0.100000 0.015250" quat="-0.70710678 0 0 0.70710678">
        <joint name="L4_yaw" type="hinge" axis="0 0 1" range="-0.61 0.61"/>
        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
        <body name="L4_femur" pos="0.012500 -0.025650 0.038400">
          <joint name="L4_pitch" type="hinge" axis="0 1 0" range="-1.4 0.52"/>
          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
          <body name="L4_tibia" pos="0.090000 0 0">
            <joint name="L4_knee" type="hinge" axis="0 1 0" range="-0.35 2.62"/>
            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
            <body name="L4_pad" pos="0.142000 0.024150 0.000000">
              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
            </body>
          </body>
        </body>
      </body>
      <body name="L5_yaw" pos="0.086603 -0.050000 0.015250" quat="-0.96592583 0 0 0.25881905">
        <joint name="L5_yaw" type="hinge" axis="0 0 1" range="-0.61 0.61"/>
        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
        <body name="L5_femur" pos="0.012500 -0.025650 0.038400">
          <joint name="L5_pitch" type="hinge" axis="0 1 0" range="-1.4 0.52"/>
          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
          <body name="L5_tibia" pos="0.090000 0 0">
            <joint name="L5_knee" type="hinge" axis="0 1 0" range="-0.35 2.62"/>
            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
            <body name="L5_pad" pos="0.142000 0.024150 0.000000">
              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
            </body>
          </body>
        </body>
      </body>
    </body>
  </worldbody>

  <actuator>
    <position name="L0_yaw" joint="L0_yaw" kp="18.0" forcerange="-2.2 2.2"/>
    <position name="L0_pitch" joint="L0_pitch" kp="26.0" forcerange="-2.2 2.2"/>
    <position name="L0_knee" joint="L0_knee" kp="24.0" forcerange="-2.2 2.2"/>
    <velocity name="L0_yaw_d" joint="L0_yaw" kv="0.35" forcerange="-2.2 2.2"/>
    <velocity name="L0_pitch_d" joint="L0_pitch" kv="0.45" forcerange="-2.2 2.2"/>
    <velocity name="L0_knee_d" joint="L0_knee" kv="0.4" forcerange="-2.2 2.2"/>
    <position name="L1_yaw" joint="L1_yaw" kp="18.0" forcerange="-2.2 2.2"/>
    <position name="L1_pitch" joint="L1_pitch" kp="26.0" forcerange="-2.2 2.2"/>
    <position name="L1_knee" joint="L1_knee" kp="24.0" forcerange="-2.2 2.2"/>
    <velocity name="L1_yaw_d" joint="L1_yaw" kv="0.35" forcerange="-2.2 2.2"/>
    <velocity name="L1_pitch_d" joint="L1_pitch" kv="0.45" forcerange="-2.2 2.2"/>
    <velocity name="L1_knee_d" joint="L1_knee" kv="0.4" forcerange="-2.2 2.2"/>
    <position name="L2_yaw" joint="L2_yaw" kp="18.0" forcerange="-2.2 2.2"/>
    <position name="L2_pitch" joint="L2_pitch" kp="26.0" forcerange="-2.2 2.2"/>
    <position name="L2_knee" joint="L2_knee" kp="24.0" forcerange="-2.2 2.2"/>
    <velocity name="L2_yaw_d" joint="L2_yaw" kv="0.35" forcerange="-2.2 2.2"/>
    <velocity name="L2_pitch_d" joint="L2_pitch" kv="0.45" forcerange="-2.2 2.2"/>
    <velocity name="L2_knee_d" joint="L2_knee" kv="0.4" forcerange="-2.2 2.2"/>
    <position name="L3_yaw" joint="L3_yaw" kp="18.0" forcerange="-2.2 2.2"/>
    <position name="L3_pitch" joint="L3_pitch" kp="26.0" forcerange="-2.2 2.2"/>
    <position name="L3_knee" joint="L3_knee" kp="24.0" forcerange="-2.2 2.2"/>
    <velocity name="L3_yaw_d" joint="L3_yaw" kv="0.35" forcerange="-2.2 2.2"/>
    <velocity name="L3_pitch_d" joint="L3_pitch" kv="0.45" forcerange="-2.2 2.2"/>
    <velocity name="L3_knee_d" joint="L3_knee" kv="0.4" forcerange="-2.2 2.2"/>
    <position name="L4_yaw" joint="L4_yaw" kp="18.0" forcerange="-2.2 2.2"/>
    <position name="L4_pitch" joint="L4_pitch" kp="26.0" forcerange="-2.2 2.2"/>
    <position name="L4_knee" joint="L4_knee" kp="24.0" forcerange="-2.2 2.2"/>
    <velocity name="L4_yaw_d" joint="L4_yaw" kv="0.35" forcerange="-2.2 2.2"/>
    <velocity name="L4_pitch_d" joint="L4_pitch" kv="0.45" forcerange="-2.2 2.2"/>
    <velocity name="L4_knee_d" joint="L4_knee" kv="0.4" forcerange="-2.2 2.2"/>
    <position name="L5_yaw" joint="L5_yaw" kp="18.0" forcerange="-2.2 2.2"/>
    <position name="L5_pitch" joint="L5_pitch" kp="26.0" forcerange="-2.2 2.2"/>
    <position name="L5_knee" joint="L5_knee" kp="24.0" forcerange="-2.2 2.2"/>
    <velocity name="L5_yaw_d" joint="L5_yaw" kv="0.35" forcerange="-2.2 2.2"/>
    <velocity name="L5_pitch_d" joint="L5_pitch" kv="0.45" forcerange="-2.2 2.2"/>
    <velocity name="L5_knee_d" joint="L5_knee" kv="0.4" forcerange="-2.2 2.2"/>
  </actuator>
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

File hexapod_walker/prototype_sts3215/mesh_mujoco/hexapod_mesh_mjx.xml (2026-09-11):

<mujoco model="hexapod_sts3215_mesh_mjx">
  <compiler angle="radian" coordinate="local" autolimits="true"/>
  <option gravity="0 0 -9.81" timestep="0.002" iterations="50" solver="Newton" cone="elliptic"/>
  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

  <default>
    <joint armature="0.0004" damping="0.01" limited="true"/>
    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
    <default class="visual">
      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
    </default>
    <default class="collision">
      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
    </default>
    <default class="foot">
      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
    </default>
    <default class="legcol">
      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
    </default>
  </default>

  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

  <worldbody>
    <light name="sun" pos="2 -1.5 2.2" dir="-0.6 0.4 -1" castshadow="true"/>
    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

    <body name="chassis" pos="0 0 0.125421">
      <freejoint name="root"/>
      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
      <inertial pos="0.00017444 -0.00042499 0.00320286" quat="-0.01850534 0.70604293 0.02762688 0.70738793" mass="1.472688" diaginertia="7.0243e-03 4.6650e-03 4.6420e-03"/>
      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

      <body name="L0_yaw" pos="0.086603 0.050000 0.015250" quat="0.96592583 0 0 0.25881905">
        <joint name="L0_yaw" type="hinge" axis="0 0 1" range="-0.61 0.61"/>
        <inertial pos="-0.00050837 -0.00118075 0.03129236" quat="0.72259406 -0.00064904 -0.03363173 0.69045370" mass="0.160953" diaginertia="8.0340e-05 6.3578e-05 5.1442e-05"/>
        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
        <body name="L0_femur" pos="0.012500 -0.025650 0.038400">
          <joint name="L0_pitch" type="hinge" axis="0 1 0" range="-1.4 0.52"/>
          <inertial pos="0.06397730 0.02399205 0.00167816" quat="-0.00959862 0.69507737 -0.01569304 0.71869955" mass="0.142545" diaginertia="1.5199e-04 1.4063e-04 3.4006e-05"/>
          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
          <body name="L0_tibia" pos="0.090000 0 0">
            <joint name="L0_knee" type="hinge" axis="0 1 0" range="-0.35 2.62"/>
            <inertial pos="0.02313589 0.02415000 -0.00000000" quat="0.00000000 0.70710678 0.00000000 0.70710678" mass="0.029727" diaginertia="3.8624e-05 3.1351e-05 8.8284e-06"/>
            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
            <body name="L0_pad" pos="0.142000 0.024150 0.000000">
              <inertial pos="-0.00590608 0.00000000 0.00000000" quat="0.50000000 0.50000000 0.50000000 0.50000000" mass="0.003000" diaginertia="1.3967e-07 1.3967e-07 3.0036e-08"/>
              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
            </body>
          </body>
        </body>
      </body>
      <body name="L1_yaw" pos="0.000000 0.100000 0.015250" quat="0.70710678 0 0 0.70710678">
        <joint name="L1_yaw" type="hinge" axis="0 0 1" range="-0.61 0.61"/>
        <inertial pos="-0.00050837 -0.00118075 0.03129236" quat="0.72259406 -0.00064904 -0.03363173 0.69045370" mass="0.160953" diaginertia="8.0340e-05 6.3578e-05 5.1442e-05"/>
        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
        <body name="L1_femur" pos="0.012500 -0.025650 0.038400">
          <joint name="L1_pitch" type="hinge" axis="0 1 0" range="-1.4 0.52"/>
          <inertial pos="0.06397730 0.02399205 0.00167816" quat="-0.00959862 0.69507737 -0.01569304 0.71869955" mass="0.142545" diaginertia="1.5199e-04 1.4063e-04 3.4006e-05"/>
          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
          <body name="L1_tibia" pos="0.090000 0 0">
            <joint name="L1_knee" type="hinge" axis="0 1 0" range="-0.35 2.62"/>
            <inertial pos="0.02313589 0.02415000 -0.00000000" quat="0.00000000 0.70710678 0.00000000 0.70710678" mass="0.029727" diaginertia="3.8624e-05 3.1351e-05 8.8284e-06"/>
            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
            <body name="L1_pad" pos="0.142000 0.024150 0.000000">
              <inertial pos="-0.00590608 0.00000000 0.00000000" quat="0.50000000 0.50000000 0.50000000 0.50000000" mass="0.003000" diaginertia="1.3967e-07 1.3967e-07 3.0036e-08"/>
              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
            </body>
          </body>
        </body>
      </body>
      <body name="L2_yaw" pos="-0.086603 0.050000 0.015250" quat="0.25881905 0 0 0.96592583">
        <joint name="L2_yaw" type="hinge" axis="0 0 1" range="-0.61 0.61"/>
        <inertial pos="-0.00050837 -0.00118075 0.03129236" quat="0.72259406 -0.00064904 -0.03363173 0.69045370" mass="0.160953" diaginertia="8.0340e-05 6.3578e-05 5.1442e-05"/>
        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
        <body name="L2_femur" pos="0.012500 -0.025650 0.038400">
          <joint name="L2_pitch" type="hinge" axis="0 1 0" range="-1.4 0.52"/>
          <inertial pos="0.06397730 0.02399205 0.00167816" quat="-0.00959862 0.69507737 -0.01569304 0.71869955" mass="0.142545" diaginertia="1.5199e-04 1.4063e-04 3.4006e-05"/>
          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
          <body name="L2_tibia" pos="0.090000 0 0">
            <joint name="L2_knee" type="hinge" axis="0 1 0" range="-0.35 2.62"/>
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

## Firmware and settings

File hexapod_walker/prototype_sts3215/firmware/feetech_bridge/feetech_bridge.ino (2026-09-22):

/*
  Feetech MCU bridge — Uno Q

  Hardware
    Serial  (USART1, D0/D1) @ 1 Mbps  → FE-URT UART header (TX–TX, RX–RX, GND)
    Serial1 (LPUART1)       @ 921600  → Linux /dev/ttyHS1 (stop arduino-router)
    Wire    (I2C2)          SDA/SCL   → GY-521 MPU-6050 (header D20/D21, 3V3)
    ST7789 TFT (bitbang SPI): SCL D13, SDA D11, RST D8, DC D9, CS D10,
      BLK D7, VCC 3.3V, GND common
      Screen module header order: GND VCC SCL SDA RES DC CS BLK.
      (TFT "SDA" is MOSI bitbang — not the I²C SDA pin)

  Autonomy (no host required):
    - Boot: splash + "linux Ns" ticker + dim "Zz" hub badge until the
      host first speaks.
    - Host watchdog: >12 s of silence after first contact → red "web
      lost Ns" + red-X hub badge; >30 s → AUTO-LIMP (torque off, IDs
      2..19) so a dead brain can't leave motors fighting. Cleared as
      soon as the host talks again.

  Line protocol (ASCII, \\n-terminated). Host owns the conversation.

    HELLO                         → HELLO feetech_bridge
    PING <id>                     → OK <id> | ERR
    SCAN                          → OK <id>,<id>,... | OK
    T <id> <0|1>                  → OK | ERR
    TA <0|1>                      → OK          (torque IDs 2..19)
    RP <id>                       → OK <pos> | ERR
    R1 <id> <addr>                → OK <byte> | ERR
    R2 <id> <addr>                → OK <word> | ERR
    W1 <id> <addr> <val>          → OK | ERR
    W2 <id> <addr> <val>          → OK | ERR
    WP <id> <pos> <spd> <acc>     → OK | ERR   (WritePosEx)
    UL <id> / LK <id>             → OK | ERR   (EEPROM unlock / lock)
    SW <n> <id> <pos> <spd> <acc> ... → OK | ERR
    PWR                           → OK <n> <I_mA> <V10> <load10>
    DI                            → OK          (hard-reinit TFT)
    DT                            → OK          (TFT self-test: W/R/G/B)
    DX line|line|...              → OK <n> <I_mA> <V10> <load10>
                                    (status text + motor-current logo lights)
    DJ <pct>|title|l1|l2|l3|foot  → OK          (full-screen job panel:
                                    26-char rows + progress bar; pct −1 =
                                    no bar; next DX restores the schematic)
    I2CSCAN                       → OK <hex>,... | OK   (Wire bus scan)
    IMU                           → OK 0x68 | ERR ...   (wake + WHO_AM_I)
    IMUR                          → OK ax ay az gx gy gz temp
                                    (raw int16; temp = raw TEMP_OUT)
    STREAM <0|1>                  → OK STREAM <0|1>  (free-run mode below)
    STREAM                        → OK STREAM <0|1>  (query)
    DBG                           → OK key=value ... (bridge counters)
    DBG RESET                     → OK key=value ... (reset then report)

  Binary fast path (same UART):
    A5 5A 'W' n  {id u8, pos i16le, spd u16le, acc u8}×n  xor
    → OK\\n | ERR\\n
    A5 5A 'F' n  {id u8}×n  xor     (n=0 → IDs 2..19)
    → A5 5A 'f' n {id,ok,pos_i16,spd_i16,load_u16,volt_u8,temp_u8,mov_u8,cur_i16}×n xor
      (Feetech syncRead of PRESENT_POSITION..CURRENT; FeedBack fallback)
    A5 5A 'P' n  {id u8}×n  xor     (n=0 → IDs 2..19)
    → A5 5A 'p' n {id,ok,pos_i16}×n xor
      (Feetech syncRead of PRESENT_POSITION only)
    A5 5A 'S' n  {id u8, pos i16le, spd u16le, acc u8}×n  xor
    → A5 5A 's' 18 {seq u16, pos_age_ms u16, imu_age_ms u16,
                    imu i16×7 (ax ay az gx gy gz temp),
                    18×{id u8, ok u8, pos i16le, spd i16le}} xor
      (SyncWrite the commands, then reply with the latest state
       snapshot — ONE host round-trip per control tick. n=0 = no
       write, snapshot only: positions + speed + IMU in one round
       trip for sense-compute-act loops.)
    A5 5A 'V' 1  {spd u16le, acc u8}  xor            (proto=2, 2026-09-22)
    → A5 5A 'v' 0 xor | ERR\n
      (Set the servo speed/acc profile the compact tick below applies to
       every servo.  Lost on MCU reset: a 'T' with no profile set answers
       ERR, never a default -- speed/acc are part of the trained contract.)
    A5 5A 'T' 18 {pos i16le}×18  xor                 (proto=2, 2026-09-22)
    → A5 5A 't' 18 {seq u16, pos_age_ms u16, imu_age_ms u16,
                    imu i16×7 (ax ay az gx gy gz temp),
                    ok bitmap u8×3 (bit k = id 2+k, LSB first),
                    18×{pos i16le, spd i16le}} xor
      (The compact control tick: same as 'S' n=18 with ids implied
       2..19 and speed/acc from 'V'.  41 bytes out + 100 back instead of
       113 + 134: 1.5 ms of wire time per tick at 921600 instead of 2.6.
       Sync-write first, then snapshot, exactly like 'S'.)

  STREAM mode (the 50–100 Hz feedback architecture, 2026-08-19):
    While STREAM 1 and the host line is idle, the MCU free-runs the
    servo bus itself: a pos+speed syncRead of IDs 2..19 plus an IMU
    read every pass (~150–250 Hz), and a full 15-byte state syncRead
    (load/volt/temp/moving/current) every FB_PERIOD_MS (~10 Hz).
    Results live in RAM caches. Host requests then return CACHED data
    with zero servo-bus wait: 'P', 'F', 'S', IMUR, PWR and DX all
    serve from the caches, so Linux never blocks on 18 servo replies
    inside its control loop. Host still owns the conversation — the
    MCU never pushes unsolicited bytes. Default OFF at boot; the
    Linux bus driver enables it right after HELLO.
*/

#include <Wire.h>
#include <SCServo.h>
#include "st7789_tft.h"

// MPU-6050 / GY-521 on header Wire (SDA/SCL = D20/D21). Not Linux I²C.
static const uint8_t MPU_ADDR = 0x68;
static const uint8_t MPU_REG_SMPLRT_DIV = 0x19;
static const uint8_t MPU_REG_CONFIG = 0x1A;
static const uint8_t MPU_REG_GYRO_CONFIG = 0x1B;
static const uint8_t MPU_REG_ACCEL_CONFIG = 0x1C;
static const uint8_t MPU_REG_ACCEL_XOUT_H = 0x3B;
static const uint8_t MPU_REG_PWR_MGMT_1 = 0x6B;
static const uint8_t MPU_REG_WHO_AM_I = 0x75;
static bool mpuReady = false;

static const uint32_t BUS_BAUD = 1000000UL;
// 921600.  2 Mbaud was tried 2026-09-22 (hexapod.local): MCU->host was clean but
// ~64 % of host->MCU lines arrived corrupted (DBG unknown_ascii) -- the Arduino
// Serial RX path here tolerates about one byte time of interrupt latency, 5 us
// at 2 M vs 11 us at 921600, and the servo/IMU passes exceed that.  Raising
// this needs FIFO/DMA RX in the loader firmware, not a sketch change.  The host
// (mcu_feetech_bus.py MCU_BAUDS) still negotiates, so the value here is the
// only thing to change if that ever lands.
static const uint32_t HOST_BAUD = 921600UL;  // Linux /dev/ttyHS1 must match
static const uint8_t ID_LO = 2;
static const uint8_t ID_HI = 19;
static const uint8_t MAX_N = 18;
// syncRead: PRESENT_POSITION_L (56) .. PRESENT_CURRENT_H (70) = 15 bytes
static const uint8_t FB_MEM_LEN = 15;
static const uint8_t POS_MEM_LEN = 2;
// PRESENT_POSITION_L (56) .. PRESENT_SPEED_H (59) — the stream fast block.
static const uint8_t POS_SPD_MEM_LEN = 4;
static bool syncReadReady = false;
static uint8_t syncReadRxLen = 0;
static uint32_t syncReadTimeoutMs = 20;

SMS_STS sts;

// FTServo readSCS waits until the buffer is full or timeout — size must match
// the packet length we request, or short (pos-only) reads burn the whole
// timeout. Timeout is per missing servo: keep it short in stream mode so one
// dead ID cannot eat the control period (20 ms legacy, ~5 ms streaming).
static void ensureSyncRead(uint8_t rxLen, uint32_t timeoutMs) {
  if (syncReadReady && syncReadRxLen == rxLen
      && syncReadTimeoutMs == timeoutMs) return;
  if (syncReadReady) sts.syncReadEnd();
  sts.syncReadBegin(MAX_N, rxLen, timeoutMs);
  syncReadReady = true;
  syncReadRxLen = rxLen;
  syncReadTimeoutMs = timeoutMs;
}

// ---- STREAM mode state (free-running acquisition caches) ----
static bool streaming = false;
static int16_t posCache[MAX_N];
static int16_t spdCache[MAX_N];       // counts/s, sign-decoded
static uint8_t posOk[MAX_N];
static uint16_t posSeq = 0;
static unsigned long posStampMs = 0;
static int16_t imuCache[7];           // ax ay az gx gy gz temp (raw)
static bool imuCacheValid = false;
static unsigned long imuStampMs = 0;
static unsigned long imuRetryMs = 0;
// A short cluster of I2C misses must not turn into the one-second
// absent-sensor recovery path. Keep using the already-initialized MPU and
// retry from the asynchronous acquisition slot until failures have persisted
// for a meaningful interval. The Linux controller still independently
// rejects attitude data older than 150 ms.
// 80 ms leaves margin beneath the host's 150 ms freshness stop even when the
// last good sample was already 12 ms old and a failing Wire transaction takes
// roughly the 50 ms worst case observed on hardware.
static const unsigned long STREAM_IMU_RUNTIME_FAIL_GRACE_MS = 80;
static uint8_t streamImuReadFailStreak = 0;
// Retry cadence after mpuReady drops. 1000 ms for a sensor that never
// answered (absent/unwired); 100 ms once it has worked, so a runtime I2C
// glitch cluster costs <~200 ms of attitude age instead of >1 s. The Linux
// runner fails closed at 150 ms IMU age and limps a standing robot when a
// stream-loss hold cannot be confirmed (seen 2026-09-10 on hexapod2:
// gyro frozen, imu_age 150->273 ms, "hold unverified; limped").
static unsigned long imuRetryBackoffMs = 1000;
static unsigned long streamImuFirstFailMs = 0;
static uint16_t fbLoad[MAX_N];        // magnitude, tenths of %
static uint8_t fbVolt[MAX_N];         // deci-volts
static uint8_t fbTemp[MAX_N];
static uint8_t fbMov[MAX_N];
static int16_t fbCur[MAX_N];          // raw, ×6.5 mA
static uint8_t fbOk[MAX_N];
static unsigned long fbStampMs = 0;
// Full-state pass cadence. Positions/speed/IMU refresh every pass
// (~150-250 Hz); current/load/volt/temp only need ~10 Hz.
static const unsigned long FB_PERIOD_MS = 100;
// During host-owned 100 Hz control, serve 'S' replies from the last fresh
// cache, then refresh pos/speed/IMU in the idle gap before the next tick.
// This keeps the read cadence near the control rate, with one-tick latency,
// while taking servo/I2C waits out of the host round-trip.
static const unsigned long HOST_S_REFRESH_DELAY_MS = 1;
static const unsigned long HOST_S_CONTROL_IDLE_MS = 30;
static const unsigned long HOST_S_MAX_CACHE_AGE_MS = 12;
static bool hostSRefreshPending = false;
static unsigned long hostSRefreshAtMs = 0;
static unsigned long hostSLastMs = 0;

static bool streaming_fb_fresh() {
  return streaming && fbStampMs != 0;
}

// Defined below (need sts / bin helpers first).
static void streamFastPass();
static void streamFullPass();
static void streamImuPass();
static void prepareSnapshotForHost();

// The host-UART RX ring is SMALLER than one 113-byte 'W'/'S' frame
// (measured 2026-08-19: a frame landing while the MCU is inside a 4-6 ms
// acquisition pass loses bytes). So passes must keep draining host bytes
// into the frame parser. Execution is DEFERRED: running a command
// mid-pass would collide on the half-duplex servo bus, so a completed
// frame is parked and run right after the pass.
static bool deferHostExec = false;
static uint8_t parkedKind = 0;  // 0 none, 1 binary frame, 2 ascii line
static void hostPump();         // drain host bytes into the parser
static void execParked();       // run a parked frame (servo bus free)

static char lineBuf[640];
static uint16_t lineLen = 0;

// ---- Bridge diagnostics: counters are read/reset by the DBG command. ----
static uint32_t dbgHostBytesSeen = 0;
static uint32_t dbgAsciiLinesCompleted = 0;
static uint32_t dbgAsciiLinesParked = 0;
static uint32_t dbgAsciiOkReplies = 0;
static uint32_t dbgAsciiErrReplies = 0;
static uint32_t dbgLineOverflow = 0;
static uint32_t dbgUnknownAscii = 0;
static uint32_t dbgBinFramesStarted = 0;
static uint32_t dbgBinFramesCompleted = 0;
static uint32_t dbgBinFramesParked = 0;
static uint32_t dbgBinFramesExecuted = 0;
static uint32_t dbgBinChecksumBad = 0;
static uint32_t dbgBinBadN = 0;
static uint32_t dbgBinBadCmd = 0;
static uint32_t dbgProfileSets = 0;      // 'V' accepted
static uint32_t dbgTickFrames = 0;       // 'T' executed
static uint32_t dbgTickNoProfile = 0;    // 'T' refused: no profile since boot
static uint32_t dbgAutoLimps = 0;        // host silent > HOST_LIMP_MS: torque cut on all servos (never reset)
static uint32_t dbgAutoLimpLastMs = 0;
static uint32_t dbgBinReplyHeaders = 0;
static uint32_t dbgDesyncResets = 0;
static uint32_t dbgSyncWriteCalls = 0;
static uint32_t dbgSyncWriteFailures = 0;
static uint32_t dbgStreamFastPasses = 0;
static uint32_t dbgStreamFullPasses = 0;
static uint32_t dbgStreamImuPasses = 0;
static uint32_t dbgStreamImuReadFailures = 0;
static uint32_t dbgStreamPosSlotFails = 0;
static uint32_t dbgStreamFbSlotFails = 0;
static uint32_t dbgStreamPosSlotHealed = 0;
static uint32_t dbgPosSlotFailById[MAX_N];  // per burst slot (id = k + 2)
static uint32_t dbgHostSnapshotRequests = 0;
static uint32_t dbgHostSnapshotCacheHits = 0;
static uint32_t dbgHostSnapshotSyncRefreshes = 0;
static uint32_t dbgHostSnapshotSyncPosRefreshes = 0;
static uint32_t dbgHostSnapshotSyncImuRefreshes = 0;
static uint32_t dbgHostSnapshotStaleCacheReplies = 0;
static uint32_t dbgHostSnapshotAsyncRefreshes = 0;
static uint32_t dbgMaxFastPassUs = 0;
static uint32_t dbgMaxFullPassUs = 0;
static uint32_t dbgMaxImuPassUs = 0;
static uint32_t dbgMaxBinExecUs = 0;
static uint32_t dbgMaxParkedWaitUs = 0;
static uint32_t dbgLastBinFrameStartUs = 0;
static uint32_t dbgLastBinFrameCompleteUs = 0;
static uint32_t dbgBinParkedAtUs = 0;
static uint8_t dbgLastBinCmd = 0;
static uint8_t dbgLastBinN = 0;

static void dbgUpdateMax(uint32_t &dst, uint32_t val) {
  if (val > dst) dst = val;
}

static void dbgResetCounters() {
  dbgHostBytesSeen = 0;
  dbgAsciiLinesCompleted = 0;
  dbgAsciiLinesParked = 0;
  dbgAsciiOkReplies = 0;
  dbgAsciiErrReplies = 0;
  dbgLineOverflow = 0;
  dbgUnknownAscii = 0;
  dbgBinFramesStarted = 0;
  dbgBinFramesCompleted = 0;
  dbgBinFramesParked = 0;
  dbgBinFramesExecuted = 0;
  dbgBinChecksumBad = 0;
  dbgBinBadN = 0;
  dbgBinBadCmd = 0;
  dbgProfileSets = 0;
  dbgTickFrames = 0;
  dbgTickNoProfile = 0;
  dbgBinReplyHeaders = 0;
  dbgDesyncResets = 0;
  dbgSyncWriteCalls = 0;
  dbgSyncWriteFailures = 0;
  dbgStreamFastPasses = 0;
  dbgStreamFullPasses = 0;
  dbgStreamImuPasses = 0;
  dbgStreamImuReadFailures = 0;
  dbgStreamPosSlotFails = 0;
  dbgStreamFbSlotFails = 0;
  dbgStreamPosSlotHealed = 0;
  for (uint8_t k = 0; k < MAX_N; k++) dbgPosSlotFailById[k] = 0;
  dbgHostSnapshotRequests = 0;
  dbgHostSnapshotCacheHits = 0;
  dbgHostSnapshotSyncRefreshes = 0;
  dbgHostSnapshotSyncPosRefreshes = 0;
  dbgHostSnapshotSyncImuRefreshes = 0;
  dbgHostSnapshotStaleCacheReplies = 0;
  dbgHostSnapshotAsyncRefreshes = 0;
  dbgMaxFastPassUs = 0;
  dbgMaxFullPassUs = 0;
  dbgMaxImuPassUs = 0;
  dbgMaxBinExecUs = 0;
  dbgMaxParkedWaitUs = 0;
  dbgLastBinFrameStartUs = 0;
  dbgLastBinFrameCompleteUs = 0;
  dbgBinParkedAtUs = 0;
  dbgLastBinCmd = 0;
  dbgLastBinN = 0;
}

static void dbgPrintKV(const __FlashStringHelper *key, uint32_t value) {
  Serial1.print(' ');
  Serial1.print(key);
  Serial1.print('=');
  Serial1.print(value);
}

static void dbgPrintKV8(const __FlashStringHelper *key, uint8_t value) {
  dbgPrintKV(key, (uint32_t)value);
}
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
void loop() {
  unsigned long now = millis();
  // A frame parked during the synchronous (non-streaming) 'S' passes
  // must still run; parked work always precedes new ring bytes.
  if (parkedKind != 0) execParked();
  // Desync guard: a torn binary frame (host retry after timeout) must
  // not eat the next frame's header as payload.
  if (binState != 0 && (long)(now - lastHostMs) > (long)HOST_BIN_DESYNC_MS) {
    dbgDesyncResets++;
    binState = 0;
    replyErr();
  }
  if (Serial1.available() > 0) {
    hostSeen = true;
    lastHostMs = millis();
    autoLimped = false;
    do {
      dbgHostBytesSeen++;
      feedHostByte((uint8_t)Serial1.read());
    } while (Serial1.available() > 0);
    return;
  }
  // A frame is in progress but the next byte has not arrived yet. Spin here
  // instead of entering a servo/I2C stream pass; otherwise the small hardware
  // FIFO can overflow before hostPump() gets another chance to drain it.
  if (binState != 0) return;
  if (streaming && hostSRefreshPending
      && (long)(now - hostSRefreshAtMs) >= 0) {
    hostSRefreshPending = false;
    // Let the 128-byte snapshot reply finish leaving the host UART before
    // the servo-bus pass starts. Measured 2026-09-10 (hexapod2): with the
    // pass starting 1 ms after the reply, host-paced 100 Hz snapshot-only
    // polling lost ~44% of bursts (always the 3rd-5th slots, IDs 4-6) while
    // free-run and write+snapshot control lost <1%.
    Serial1.flush();
    // Frequent S requests otherwise keep taking this branch and the
    // 30 ms quiet branch below, starving current/load/voltage/temperature
    // acquisition indefinitely. A full pass also refreshes positions and
    // speed, so use it instead of the fast pass when health is due.
    if (now - fbStampMs >= FB_PERIOD_MS) {
      streamFullPass();
    } else {
      streamFastPass();
    }
    streamImuPass();
    dbgHostSnapshotAsyncRefreshes++;
    if (parkedKind != 0) {
      execParked();
      return;
    }
    return;
  }
  if (streaming && hostSLastMs != 0
      && (long)(now - hostSLastMs) < HOST_S_CONTROL_IDLE_MS
      && now - fbStampMs < FB_PERIOD_MS) {
    return;
  }
  if (streaming) {
    // Free-running acquisition while the host line is idle. ONE pass per
    // loop() iteration keeps worst-case host-command latency to a single
    // pass (~3-8 ms). Host bytes arriving mid-pass are pumped into the
    // parser (hostPump) and a completed frame runs right after the pass.
    if (now - fbStampMs >= FB_PERIOD_MS) {
      streamFullPass();   // low-rate: current/load/volt/temp (~10 Hz)
    } else {
      streamFastPass();   // pos+speed, all 18 servos (~150-250 Hz)
      streamImuPass();
    }
    if (parkedKind != 0) {
      execParked();
      return;
    }
  }
  if (!hostSeen) {
    // Boot counter until Linux first speaks; afterwards the host owns
    // the panel (DX schematic / DJ job screens).
    tft::bootTick(now);
    return;
  }
  // 2026-09-22 BUG (hexapod2 collapsed standing, twice, ~1 min after a
  // move, no software cause): `now` is sampled at the top of loop(), but
  // hostPump() inside the stream passes above updates lastHostMs with a
  // LATER millis().  `now - lastHostMs` then wraps to ~4e9 as unsigned,
  // "host lost for 49 days", and every servo was torque-cut although the
  // host had just spoken.  Re-sample the clock and compare signed, so a
  // lastHostMs in the future reads as "heard from the host just now".
  const long sinceHostMs = (long)(millis() - lastHostMs);
  if (sinceHostMs > (long)HOST_LOST_MS) {
    static unsigned long lastWarnMs = 0;
    if (now - lastWarnMs >= 1000) {
      lastWarnMs = now;
      tft::hostLostTick((unsigned long)sinceHostMs / 1000UL);
    }
    if (!autoLimped && sinceHostMs > (long)HOST_LIMP_MS) {
      autoLimped = true;
      dbgAutoLimps++;              // 2026-09-22: the host had no way to know this happened
      dbgAutoLimpLastMs = now;
      for (int id = ID_LO; id <= ID_HI; id++) {
        sts.EnableTorque((u8)id, 0);
      }
      Serial1.println(F("AUTOLIMP host silent"));   // lands in the host's bus trace (pre_a5_lines)
      tft::autoLimpPaint();
    }
  }
}

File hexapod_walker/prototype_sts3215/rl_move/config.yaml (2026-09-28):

# Phase-1 stationary balance — see RL_PLAN.md

control:
  # 100 Hz is the trained contract of every NEW policy (operator order
  # 2026-08-24, fb_20260824T174619_c49b7e: "make all new models use
  # 100hz"). This value feeds the SIM env dt (sim_env.py) AND the robot
  # runner's default rate, so training and deploy defaults do not drift.
  # The live robot runner keeps policy obs/action/phase/safety at this cadence,
  # but joystick drive may use control.drive_write_hz (default 50 Hz in
  # linux_control/rl_policy.py) for all-servo bus writes when live telemetry
  # shows the transport cannot complete one full-body write every 10 ms.
  # PLAYBACK: linux_control/rl_policy.py adapts to the selected policy's
  # own meta.control_hz / policy_hz; legacy/no-rate exports are treated
  # as 25 Hz brains instead of being played 4x fast.
  hz: 100
  # Robot runner only: interpolate a slower trained policy target into
  # faster servo-stream writes. This does not change sim dt, policy obs,
  # phase clocks, or action costs; with 100 Hz policies this is normally
  # equal to control.hz and therefore disabled.
  inner_hz: 100
  # Robot joystick drive only: all-servo target writes. This deliberately does
  # not change the selected policy's trained control rate.
  drive_write_hz: 50

episode:
  seconds: 5
  settle_seconds: 2.5          # unused unless allow_stand_blend
  # Abort before any SyncWrite if |roll| or |pitch| exceeds this.
  preflight_max_tilt_deg: 12.0
  # Always hold current pose — never yank to default +20/+80.
  hold_current_pose: true
  allow_stand_blend: false     # autonomous stand later; not Phase 1
  # Require plant_pose.json with joints_deg from capture_plant.
  require_captured_plant: true
  max_plant_delta_deg: 15.0    # refuse start if farther than this from plant

actions:
  max_roll_deg: 5.0
  max_pitch_deg: 5.0
  # Height channel must span the rise task's crouch (knee cap raised to
  # 150 deg, so the body-IK can genuinely crouch now).
  max_height_mm: 80.0
  # X/Y must move the CoM a meaningful fraction of the ~120 mm support
  # polygon or the unload (weight-shift) task is physically impossible.
  max_x_mm: 40.0
  max_y_mm: 40.0

# Goal-conditioned lean / rise / weight-shift task (sim/goal_task.py).
goal:
  p_hold: 0.10                 # episode-mode sampling probabilities
  p_lean: 0.15
  p_track: 0.15
  p_unload: 0.20
  # Rise is the one unsolved skill (belly-start 0/6 after run 3) —
  # overweight it until it lands, then rebalance.
  p_rise: 0.35                 # start at ZERO pose (belly down), stand up
  # Canary task: from the plant stance, follow a height ramp UP. The
  # single simplest goal in the set — if the policy can't hit ~100% on
  # this quickly, the height pathway (obs/reward/IK) is broken, not
  # under-trained.
  p_raise: 0.15
  raise_height_mm: [10.0, 30.0]
  max_ref_deg: 4.0             # capped to actions.max_roll/pitch_deg
  track_period_s: [2.5, 8.0]   # slow enough to follow through latency
  ramp_s: 0.75                 # ease references in from zero
  rise_height_mm: [30.0, 70.0] # lift the body this far off the belly
  # Curl window: a full curl takes ~5-6 s through the real servo profile
  # (measured: forced curl=0.6 needs 4 s for 60% of the distance). At
  # hold 3 s the ramp outran any honest curl attempt and the height-
  # progress term CHARGED the robot while it was still preparing.
  rise_hold_s: 5.0             # height ref stays 0 while legs curl in
  rise_ramp_s: 4.0             # then ramps 0 -> rise this fast
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

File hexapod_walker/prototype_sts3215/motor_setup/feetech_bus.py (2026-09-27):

#!/usr/bin/env python3
"""Arduino Uno Q direct driver for the FEETECH STS3215 serial-bus servos.

June 2026 redesign: the prototype dropped the Arduino Mega + 2x PCA9685
PWM stack (and the AS5600 add-on encoders) in favour of 18x FEETECH
STS3215 (ST-3215-C018, 12 V / 30 kg-cm) smart serial-bus servos.  Each
servo carries its own 12-bit magnetic encoder and reports position,
speed, load, voltage, current and temperature back over the bus, so the
robot gets closed-loop joint feedback "for free" with NO external
sensors and NO PWM driver boards.

Topology (see ../firmware/WIRING.md):

    Arduino Uno Q UART --half-duplex TTL bus, 1 Mbps-->
                  servo 1 --> servo 2 --> ... --> servo 18
    12 V (3S LiPo / bench supply) injected on the bus V+ rail per leg,
    common ground with the Uno Q.  The Uno Q (on-board Linux SoC + MCU)
    runs this file AND drives the half-duplex STS3215 bus directly: it
    replaces BOTH the Raspberry Pi and the separate USB->TTL bus adapter
    (no FE-URT-1 / Waveshare adapter).  This file is the ONLY controller
    -- the Uno Q talks the STS protocol directly; there is no other
    microcontroller in the loop.

Joint model (unchanged from the old Arduino bridge so poses, the MuJoCo
sim and the docs all still line up):

    joint = leg * 3 + axis          leg = 0..5
    axis 0 = yaw, axis 1 = hip pitch, axis 2 = knee pitch
    logical joint j  ->  servo ID (j + 2)   [IDs 2..19, set once with `setid`]
    ID 1 is reserved / never assigned -- every STS3215 ships as ID 1, so
    leaving it free means a factory-fresh servo can always join a live
    daisy-chain without colliding.

Per-axis SAFE software limits (MUST match mujoco_prototype._leg_xml and
check_workspace_self_collision in _verify_prototype.py):

    yaw:        -35 .. +35 deg
    hip pitch:  -80 .. +40 deg
    knee pitch: -20 .. +150 deg

Trims: the old Arduino bridge used to persist per-joint trims in
EEPROM.  Trims now live in a JSON file next to this script
(``feetech_trims.json``) on the Uno Q and are applied in software
before the angle->step conversion.

Examples
--------

    # One-time per servo (factory ID is 1; robot IDs are 2..19):
    python feetech_bus.py --port /dev/ttyACM0 setid --from 1 --to 4

    # Discover everything currently on the bus
    python feetech_bus.py --port /dev/ttyACM0 scan

    # Centre every joint (0 deg)
    python feetech_bus.py --port /dev/ttyACM0 centre

    # Move joint 0 to +20 deg, eased
    python feetech_bus.py --port /dev/ttyACM0 joint 0 20 --sweep

    # Standing tripod pose on all 18 joints
    python feetech_bus.py --port /dev/ttyACM0 stance

    # Live feedback table (the whole point of the swap)
    python feetech_bus.py --port /dev/ttyACM0 feedback --watch

    # Limp the robot (torque off) so you can pose it by hand
    python feetech_bus.py --port /dev/ttyACM0 relax
"""

from __future__ import annotations

import argparse
import json
import math
import sys
import time
from pathlib import Path

_PROTO_ROOT = Path(__file__).resolve().parents[1]
if str(_PROTO_ROOT) not in sys.path:
    sys.path.insert(0, str(_PROTO_ROOT))

from hexapod_core.joint_frame import (  # noqa: F401 (re-exported,
    FACTORY_SERVO_ID, FRAME_ROBOT_ABS, JOINT_CONTRACT, N_JOINTS,
    SERVO_ID_OFFSET, SERVO_IDS, joint_of_servo, servo_id,
    FRAME_SERVO_RELATIVE, robot_abs_to_servo_relative,
    servo_relative_to_robot_abs)

# ---------------------------------------------------------------------------
# Joint model (mirrors firmware/prototype_servo_bridge.ino and mujoco_prototype)
# ---------------------------------------------------------------------------

# Per-axis safe limits, axis = joint % 3 (0 yaw, 1 hip, 2 knee).
AXIS_LIMITS_DEG = {
    0: (-35.0, 35.0),    # yaw
    1: (-80.0, 40.0),    # hip pitch
    2: (-20.0, 150.0),   # knee pitch (Aug 2026: operator raised from 80 —
                         # the 80° cap made the plant pose the bottom of
                         # the envelope, no crouch possible)
}
TRIM_LIMIT_DEG = 30.0

# STS3215: 0..4096 counts over a full 360 deg, neutral ("centre") = 2048.
STS_COUNTS_PER_REV = 4096
STS_CENTRE_COUNT = 2048
COUNTS_PER_DEG = STS_COUNTS_PER_REV / 360.0   # 11.3778 counts/deg

# Per-joint mechanical direction.  +1 means servo CW (increasing count) is
# the positive joint direction; -1 flips it.  Left/right legs and the
# yaw/hip/knee horn orientations may need individual flips -- calibrate on
# the bench with `feedback` + `joint`, then set these.  Default +1.
JOINT_SIGN = [1] * N_JOINTS

# Motion profiles (STS WritePosEx / SyncWritePosEx).
# IMPORTANT: Feetech treats speed==0 as MAX speed, not "stop".  Never pass
# 0 when you mean a gentle hold — use HOLD_SPEED / normalize_speed().
STS_SPEED_MAX = 0           # Feetech magic: unlimited / max
DEFAULT_SPEED = 1500        # walk / general move (steps/s)
DEFAULT_ACC = 30            # 0..255, *100 steps/s^2
HOLD_SPEED = 250            # re-command current pose / freeze (gentle)
HOLD_ACC = 40
WALK_SPEED = DEFAULT_SPEED
WALK_ACC = DEFAULT_ACC

BAUD_DEFAULT = 1_000_000   # STS3215 factory default


def normalize_speed(speed: int | None, *, allow_max: bool = False) -> int:
    """Coerce a Feetech goal-speed argument safely.

    ``speed is None`` → ``DEFAULT_SPEED``.
    ``speed == 0`` without ``allow_max`` → ``HOLD_SPEED`` (0 means MAX on
    STS firmware — a common footgun for "hold still" callers).
    """
    if speed is None:
        return DEFAULT_SPEED
    speed = int(speed)
    if speed == 0 and not allow_max:
        return HOLD_SPEED
    if speed < 0:
        return HOLD_SPEED
    return speed


def normalize_acc(acc: int | None) -> int:
    if acc is None:
        return DEFAULT_ACC
    return int(max(0, min(254, acc)))

TRIM_PATH = Path(__file__).resolve().parent / "feetech_trims.json"

# Learned plant (stand home) from contact calibrate.  Prefer linux_control/logs.
# Default stand when no plant_pose.json.
# Sit zero = femur straight out (0°).  A real stand puts the femur down and
# the tibia near the measured floor contact family: hip ≈ +19° and knee
# ≈ +28° under the absolute-tibia convention.  The old +80° fallback was
# from the retired serial ``hip+knee`` geometry and drives far too deep.
DEFAULT_STAND_HIP_DEG = 19.0
DEFAULT_STAND_KNEE_DEG = 28.0
PLANT_PATH_CANDIDATES = (
    Path(__file__).resolve().parent.parent / "logs" / "plant_pose.json",
    Path.home() / "hexapod_sts" / "linux_control" / "logs" / "plant_pose.json",
    Path.home() / "hexapod_sts" / "logs" / "plant_pose.json",
    Path(__file__).resolve().parent / "plant_pose.json",
)


def axis_of(joint: int) -> int:
    return joint % 3


def clampf(x: float, lo: float, hi: float) -> float:
    return lo if x < lo else hi if x > hi else x


def joint_limits(joint: int) -> tuple[float, float]:
    return AXIS_LIMITS_DEG[axis_of(joint)]
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

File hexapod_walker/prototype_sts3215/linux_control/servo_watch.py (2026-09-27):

"""Background servo health watchdog: liveness + over-temperature.

Every few seconds it does ONE MCU round-trip (``read_all_feedback`` — a
single bulk transaction covering all 18 expected servos) and publishes:

- which expected servos are MISSING (drives the TFT error panel and the
  ``servo`` block in ``/api/robot``), and
- each servo's temperature. Any servo at/above ``SHUTOFF_C`` for three
  consecutive watchdog reads gets its torque cut and is latched ``tripped``
  until it cools below
  ``CLEAR_C``. Torque is never re-enabled automatically — that is the
  operator's call (ARM again once it has cooled).

The STS3215 also has its own EEPROM max-temp limit (~70 C default) that
unloads torque in firmware; this watchdog trips earlier (65 C, matching
``rl_move`` safety), logs the event, and puts it on the screen instead of
failing silently (2026-08-06: a knee cooked with no warning anywhere).

Bus contention: the MCU bus serializes transactions internally, so a
watch read only adds a brief latency blip to a running job's loop. While
a bench job owns the bus we still watch, just less often (``BUSY_PERIOD``)
— overheat risk is highest exactly when something is driving the motors.
"""
from __future__ import annotations

import threading
import time
from typing import Any, Callable

from feetech_bus import N_JOINTS, joint_to_servo_id

WATCH_PERIOD_S = 3.0    # idle cadence
BUSY_PERIOD_S = 5.0     # while a demo/job owns the bus (10.0 until 08-11:
                        # with the old sparse debounce that meant long periods
                        # blind time exactly while motion makes heat — two
                        # hips sailed past shutoff mid-glide before anything
                        # bus-side noticed)
WARN_C = 55             # show on screen / web
SHUTOFF_C = 65          # cut that servo's torque (rl_move safety uses 65)
CLEAR_C = 50            # un-latch "tripped" once cooled below this
STALE_S = 30.0          # snapshot older than this counts as unknown
TEMP_TRIP_READS = 3     # same joint; rejects consecutive corrupt bus bytes
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

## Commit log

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2026-08-29 sts3215: component-boundaries refactor — hexapod_core, bench_api api/ split, deploy manifest, archive frozen builds
    One coherent commit so the orchestrator .code_sha gate keeps pods consistent.
    No behavior changes to reward/env/training code; full local bank vs the
    pre-refactor baseline has an identical failure set (the 86 known-red
    control.hz tests) with more passes.
    - hexapod_core/: new shared package for the gait/choreography modules both
    the robot server and the sim reached into each other for (tripod/noslip/
    se2 gaits, sim_gait_compat, walk_ready_transition, dance_script,
    quad_walk, joint_frame). sys.path shims replaced with package imports;
    legacy stubs at the old locations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
    [layout_manifest.csv, m2p5x8_shcs.scad, m2x8_shcs.scad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]
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2026-08-30 Document RL status and hybrid demos
    Add operator-facing RL status brief docs, full-mesh drive/hybrid demo helpers, stable learned-stand handoff fixes, and browser controls/docs for scripted tuck stand/lower.
    [hexapod_mesh_mjx.xml]
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2026-09-08 linux_control: journal high-level commands with their controller
    Several controllers drive this robot -- Robot Lab, the Mac hub on :8898, and
    a browser on whichever laptop is nearby -- but nothing recorded which one
    issued a given command. events.jsonl holds one ring sized for a single
    debugging session, and continuous GET polling of /api/feedback, /api/setup
    and /api/rl/drive evicted it within about ten seconds, so the record of a
    real stop event was already gone by the time anyone looked.
    Add a separate journal of state-changing commands only, each attributed to a
    controller by explicit X-Hexapod-Controller header, then a configurable
    peer->name map, then a user-agent hint, then the bare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
    [command_journal.py, event_log.py, web_drive.py]
2026-09-08 linux_control: record on the robot which deploy is running
    Anyone may deploy, deliberately. What was missing is the ability for another
    process to find out which deploy is live and when it landed: deploy_lock.sh
    keeps a history at ~/.hexapod/deploy.log, but that is workstation-local, so
    Robot Lab, the Mac hub and a second laptop each see only their own deploys.
    stage_deploy_tree now writes deploy_record.json into the staged tree, so the
    receipt ships with the code it describes and covers both the ssh and adb
    transports. It is generated last, after caches and macOS junk are removed and
    excluding itself, so staged_tree_sha256 is the deterministic identity of what
    actually shipped -- independe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
    [deploy_record.py, event_log.py, web_drive.py]
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2026-09-08 cad: drop sys.path shims that only inserted the prototype root (56 scripts)
    The CAD pipeline scripts (build_all-style entry points, scripts/, tools/,
    concepts/, strength/, apriltag_lids/, ...) each inserted the prototype root
    so `import hexapod_prototype` works when run from their own directory via
    run.sh. The editable install provides that directory now. Removed only
    blocks whose inserted paths all resolved to the covered set; 13 files keep
    a block that also inserts tools/, scripts/, cad_step_test/ or a concept
    sibling dir, and files without a __main__ guard, mesh_mujoco/, motor_setup/,
    hexapod_core/ and linux_control/ (pod- and robot-side runtimes) were left
    alone on purpose.
    Verified: ev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
    [bus_bench.py, feetech_bus.py, track_apriltags.py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]
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2026-09-08 revert shim removal in linux_control/ and motor_setup/ (robot-side runtimes)
    The cad tier's file list accidentally included 12 modules that are deployed
    to the Uno Q. Their inserts are redundant there too (systemd sets PYTHONPATH
    to the same directories) but they are hardware-side code that cannot be
    verified from the Mac, so restore the origin/main versions. Only test files
    and dev_loop.sh change under linux_control/ now.
    [bus_bench.py, feetech_bus.py, track_apriltags.py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]
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2026-09-09 control: report measured loop cadence including logging and status work
    Observe tick-start intervals separately from configured policy rates and the narrower service timer. Add bounded recent p95/p99 diagnostics, all-run mean/max/rate and late interval counts, per-row period_ms, and live measured_loop_hz. Keep scheduling and safety thresholds intact.
    Validation: 2842 fast tests passed with 21 skipped and 1 expected failure; robot-check and robot-unit-check passed. Fourteen focused clock/timing tests also pass after review. Percentiles use only the latest 1000 intervals; cumulative loop cadence includes hold/waiting iterations and is not servo-write throughput.
    [rl_policy.py]
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2026-09-10 hexapod2: make 100 Hz RL deployable (bridge firmware + runner grace) and document the timing root causes
    Live session on the second build (hexapod2.local, 2026-09-10) found four
    stacked causes behind the recurring "100 Hz timing overrun" trips, none of
    them the policy rate:
    - feetech_bridge.ino: streamFastPass() gets the same per-id direct-read
    fallback streamFullPass() had, bounded to a 3 ms IOTimeOut (the library
    default of 100 ms stalled the host link for up to 200 ms); the
    full-pass fallback is bounded the same way; the host-triggered refresh
    pass now waits for the snapshot reply to finish transmitting
    (Serial1.flush()), which removed a TX/refresh collision that dropped
    ~44%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
    [feetech_bridge.ino, rl_policy.py]
2026-09-10 premade_chorn_56: reinforce tibia root and upper-bearing load path; add rear carrier fastener
    Operator's in-progress concept work checked in as-is (design spec, FEA
    material/load JSONs, regenerated STLs, geometry report, BuildViz scene)
    together with the push_cloud_buildviz.py changes it relies on.
    [tibia_socket_premade_chorn.3mf]
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2026-09-10 sysid runner: start-pose gate 3 -> 8 deg to clear measured gravity droop
    Eleven whole-body runs on 2026-09-10 died before tick one with 'joint N off
    by 3.0-3.8 deg after glide (tol 3)'. The per-leg and whole-body ladders put
    loaded hip/knee droop at 3.4-3.8 deg; the gate was rejecting the robot's
    own compliance. Jams and wrong zeros show as 20-30+ deg and still trip.
    Not yet deployed to the robot.
    [sysid_runner.py]
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2026-09-10 hexapod2: stop dropping a standing robot through safe_zero; IMU dropout tolerance
    Stand/lower routing (api/demos.py, api/zero.py, new test_upright_routing.py):
    - _normal_standing_pose per-joint tolerance 25/35 -> 60 deg (constant
    UPRIGHT_MAX_DELTA_DEG) with an explicit folded-under exclusion. After an
    RL or scripted walk one hip routinely rests 26-45 deg from walk-ready on a
    plainly standing robot; the old limits classified that as a recovery pose
    and routed it to safe_zero, whose first stage straightens LOADED legs
    outward and drops the chassis onto its belly (nine times on 2026-09-10,
    on video in the Robot Lab hexapod2 runs). Upright-but-off now takes the
    walk-ready re-plant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
    [feetech_bridge.ino, rl_policy.py]
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2026-09-10 sysid_runner: give the start-pose glide its own current budget
    The L4 ladder did not fail on a jam and did not fail on the post-glide
    pose gate. Run 57963c62fd19 died at glide tick -88, 0/430 protocol ticks
    run: "joint 14 overcurrent 1.38 A (limit 0.75, 3 consecutive polls)".
    The robot started folded on the carpet (L4 knee 120 deg), so the glide
    to the protocol's all-zero start pose was a 10 s whole-body unfold with
    feet carrying body weight; joint 14 climbed 0.73 -> 1.38 A extending the
    loaded knee and was judged against 0.75 A, which is the per-leg ladder's
    QUASI-STATIC MEASUREMENT budget, not a budget for the entry move. Every
    protocol in the per-leg sweep carries the same 0.75 A, so any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
    [sysid_runner.py]
2026-09-10 safe_zero: a no-force position error is ground contact, not a jam
    Diagnosis: the l4_vertical_ground_load_ladder_v1 pre-roll limped twice
    in safe_zero's executor, not in the sysid runner's glide. The trip text
    is byte-for-byte safe_zero.py's "not turning" no-progress guard:
    zero (7.5 s): LIMP - L0 knee not turning: stuck 11 deg from target
    for 2.3 s - possible mechanical jam or wrong zero
    zero (4.1 s): LIMP - L4 knee not turning: stuck 119 deg from target
    for 2.3 s - possible mechanical jam or wrong zero
    Both fired at 0.0 A peak current and a flat 38 C, with the wide camera
    showing a belly-down robot and no mechanical fault. That guard was
    purely position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
    [sysid_runner.py]
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2026-09-11 safe_zero: the 15 deg droop tolerance is confirmed, not marginal
    The plan asked whether the first zero attempt settles once the L0 knee
    residual (11 deg) is tolerated, or whether another knee simply becomes
    the new worst joint at the stage timeout. The lab already answered it and
    no threshold needed to move.
    After the GROUND_DROOP_TOL_DEG = 15 deploy, three consecutive recoveries
    reported "zero=done - at zero (safe)", and the l4_vertical_ground_load_
    ladder_v1 re-run (run 44391a01993f, 00:06 UTC 09-11) finished 430/430
    ticks with no trip. That run's trace settles the "new worst joint"
    question with numbers instead of a hypothesis: the glide brought the
    robot down from knees at 80-93 deg (L4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
    [sysid_runner.py]
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2026-09-11 rl drive: an IMU-only dropout holds the robot instead of limping it
    Stream-loss fail policy (linux_control/rl_policy.py):
    - _stream_loss_hold_sample_ok: a stale imu_age_ms no longer rejects a hold
    confirmation. Fresh, advancing servo positions plus the pose, current,
    temperature and load envelopes are still required; only the relative-tilt
    check is skipped and the sample is flagged imu_blind (drive status says
    "IMU blind"). Stale pos_age_ms still refuses.
    - The hold model now takes the same confirm-then-hold path as walking on
    "feedback stale during stream" / "feedback lost during hold" instead of
    limping immediately.
    Why: on hexapod2 (2026-09-10) an I2C dropout froze the IMU ca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
    [rl_policy.py]
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2026-09-11 sysid: a sysid job owns the result slot, so its error reaches the client
    The L3 run (861abfec61f8) reported ok=True with ticks None/None and no
    CSV. The protocol file is not the cause: l3_air_radial_shear_hysteresis_
    control_v1 validates, materializes 780 ticks at 10 Hz, hashes to the
    recorded deafc345719f, and moves joints 10/11 exactly as the working L4
    v2 moves 13/14 and L1 v1 moves 4/5. Nor did it run for 78 s — that was
    the planned duration printed at launch; its vision sidecar covers 2.6 s
    and no sysid CSV was ever written, so run_sysid_protocol returned before
    it opened one (dead joint / servo not answering / telemetry admission).
    What hid that error: calibrate_state() did not list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
    [calibrate.py]
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2026-09-11 sysid_runner: one corrupted current byte must not end a ladder
    Diagnosis: the runner's hard-ceiling current check had no upper
    plausibility bound and no confirmation, so a single decode glitch
    latched a trip. On 2026-09-10 16:59 the l2_ground_radial_shear_
    amplitude_ladder_v1 run died on "joint 0 overcurrent 126.46 A (hard
    limit 3.00)" while the same poll cycle's segment snapshots read
    peak_current_a 0.0 / 0.013 A and a flat max_temp_c 38.0 — a corrupted
    current byte on the known-flaky joint 0 (servo ID 2), not a jam. The
    bus cannot deliver 126 A. Worse, the check was not even fresh-gated:
    last_fb is cached ~3 ticks between 10 Hz polls, so the bad byte was
    re-read for several ticks. The 0.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
    [sysid_runner.py]
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2026-09-12 Never drop a standing robot: sysid runner holds at the end, API steps down, recovery ladder steps down first
    The runner limped unconditionally at the end of every run, so every stand
    protocol (and every trip while standing) ended with the robot falling onto
    its belly. It now restores the torque limit, re-writes the present pose and
    leaves torque on; the API worker classifies the pose with the demos stand
    router's gate and plays the STEP sit-down inline for a standing robot, limps
    a belly one as before, and keeps holding if the step-down failed or the
    operator aborted. The lab's recovery ladder gets a rung 0: standing -> STEP
    down before the zero blend that straightens loaded legs.
    Co-Author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
    [sysid_runner.py]
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2026-09-13 Hold back isolated servo-temperature byte glitches at the MCU bus layer
    About 1.5 % of FeedBack reads carry a wrong temperature byte for one read
    while the rest of the record is fine. Report the last accepted value with
    the raw byte in temp_raw_c until a second read agrees.
    [mcu_feetech_bus.py]
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2026-09-14 robot: let /api/set_zero take a list of servo ids
    redefine_zero_here already accepted ids; the route always calibrated every
    live servo. A single joint whose zero drifted (hexapod1 L0 knee read 66 deg
    and L1 hip 45 deg while lying flat on 2026-09-14, so every stand-up drove L0
    knee into a limit at 3 A) could only be fixed by re-zeroing the whole robot.
    POST /api/set_zero with {"ids": [4, 6, 7]} now calibrates just those; no body
    keeps the old behaviour.
    [web_drive.py]
2026-09-14 mcu bus: remove the legacy synchronous path; wrong firmware is an error
    The driver sent STREAM 1 after HELLO and, when the sketch answered ERR,
    silently used the legacy synchronous path (write_all + read_all_positions
    + read_imu, 9-13 ms per 18-servo read). That made 100 Hz impossible while
    looking like a slow policy and hid for weeks
    (rl_docs/HARDWARE_100HZ_TIMING_2026-09-10.md, Cause 1).
    Now the STREAM handshake is mandatory:
    - McuFeetechBus.__init__ requires exactly "OK STREAM 1". Any other explicit
    reply raises McuFirmwareError naming the fix
    (firmware/flash_feetech_bridge.sh arduino@<robot>.local). An empty reply
    keeps the bounded bb2071e98 boot-race retry (3 attempts) and then r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
    [bus_bench.py, calibrate.py, common.py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]
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2026-09-14 Use the joint_frame contract for joint/servo index math (robot, tools, sysid)
    Replace hand-rolled `3 * leg + k`, `j // 3` / `j % 3`, `j + 2` and
    `range(2, 20)` with joint_index / leg_of / axis_of / leg_joints /
    servo_id / joint_of_servo / SERVO_IDS. No behavior change intended;
    outputs are the same integers.
    hexapod_core/quad_walk.py, dance_script.py
    motor_setup/urt2_bench.py, inplace_demos.py, wire_harness_plan.py
    linux_control/mcu_feetech_bus.py (id math only), api/core.py,
    api/demos.py, api/standup.py, api/zero.py, motor_setup_api.py,
    rl_policy.py (drops the `lambda j: j + 2` fallback),
    drive_controller.py (SERVO_IDS for the live scan)
    tools/full_robot_viz_build.py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
    [common.py, core.py, drive_controller.py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]
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2026-09-14 robot bus: make the remaining quiet fallbacks loud or remove them
    Follow-up to the legacy-path removal: every other place in the servo-bus
    stack that caught a failure and carried on.
    Removed (fail loud):
    - open_feetech_bus: when an MCU port (/dev/ttyHS*) exists, open it and
    never drift onto a USB adapter if the HELLO probe fails. The probe took
    one 1.2 s shot and, without --port mcu, skipped the constructor's boot
    retry rounds entirely and could swap transports silently.
    Kept, but printed at WARNING with a counter:
    - mcu_feetech_bus.reload_imu_calib / reload_imu_mount: an import or parse
    failure now says so instead of reading as "no calibration"/"normal mount".
    - mcu_feetech_bus._i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
    [drive_controller.py, mcu_feetech_bus.py, sysid_runner.py]
2026-09-14 mcu_feetech_bus: route the last three `sid - 2` sites through joint_frame
    Caught by the new source scan: the per-servo report decoder, the bulk
    position reader and _read_pos_counts still computed `int(sid) - 2` and
    range-checked the result. They now test `sid in SERVO_IDS` and call
    joint_of_servo; same accept/reject set, same joints. Id math only.
    wire_harness_plan.py docstrings: point at joint_frame.servo_id and fix
    "servo_id (int 1 .. 18)", which contradicted the "IDs 2..19" beside it.
    [mcu_feetech_bus.py]
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2026-09-14 mcu bus: bounded, loud MPU wake from read_imu; drop dead probe/P code
    Removing the IMUR fallback also removed the only thing that woke a
    sleeping MPU-6050: after a power glitch the sensor boots asleep, I2C reads
    succeed and return zeros, and the firmware caches the zeros as a valid
    fresh sample (streamImuPassInner only re-inits on a FAILED read). The host
    sees imu=None with a valid imu_age_ms. On exactly that signature read_imu
    now sends one "IMU" (WHO_AM_I + PWR_MGMT_1 wake) at most every 2 s,
    prints a WARNING and counts it (imu_wake_attempts); the call still returns
    None and the next snapshot carries the real sample. An invalid age
    (0xFFFF, sensor absent / I2C failing) is left to the firmw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
    [mcu_feetech_bus.py]
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2026-09-15 Split the CAD pipeline out to lukas/hexapod-cad; the sim keeps frozen geometry and tracked mesh assets
    Mechanical design code was 40k lines and 30 MB that no control, sim or RL
    module imported, except for 27 dimensions and a mesh path helper that the
    MuJoCo primitive model read from hexapod_prototype.py. Those are now
    hexapod_core/geometry.py (frozen values; build_xml() output is byte-identical
    before and after the swap), and the as-built mesh model that training uses by
    default (env.model_source: mesh) is tracked here as a build product:
    mesh_mujoco/assets/*.stl + hexapod_mesh.xml, regenerated from HEAD CAD right
    before the split and identical to the copies every Mac had built locally.
    Mov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
    [aluminum_bottom_spreader_ring.stl, aluminum_radial_rib.stl, aluminum_standoff_sleeve.stl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]
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2026-09-18 motor swap: commission a replaced servo from the laptop; retire the bundled registry
    A fresh STS3215 answers on ID 1 with a factory zero. Until now the only way
    to move it into its slot was the /setup web page, and the zero/verify steps
    lived in a script under ~/.hexapod. linux_control/motor_swap.py drives the
    robot's own API for the whole sequence (status -> assign -> zero -> check
    with an optional camera frame-diff) and refuses while armed. plan_swap() is
    the one decision (which slot, which id) and has a test.
    Retires motor_setup/motor_setup_registry.json from git and the
    motion_telemetry fallback that read it: registry.py already says
    assignments are robot-local data in ~/.local/share/he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
    [motor_setup_registry.json]
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2026-09-18 gait sweep: head back toward the start once the chassis tag drifts, so long passes stay under the camera
    Alternating direction alone let hexapod1 walk 50 cm to the frame edge today when
    half the reverse passes were refused. With --chassis-tag the next direction now
    depends on the live floor position from the camera session: alternate inside
    --max-drift-mm (300) of the sweep start, otherwise repeat or reverse the last
    direction according to whether it brought the robot closer. Tested rule.
    [gait_sweep.py]
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2026-09-18 fleet: start-of-session robot status + robot->camera map, and a hardware checklist
    motor_swap.py and gait_sweep.py cover mid-session work but nothing answered the
    three questions that a session should open with, and getting them wrong cost 40
    minutes on 2026-09-18: which robot has the un-set-up motor, which camera
    actually shows a given robot, and did anything stray drive a robot already.
    - fleet.py status: polls the whole fleet (names are ambiguous here), prints
    servo count / armed / new-motor verdict via plan_swap / bus volts / the last
    few attributed commands. Read-only.
    - fleet.py eye <robot>: the camera source that frames THAT robot, so the
    stale "cam 1 = hexapod2" note cannot mi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
    [fleet.py]
2026-09-18 gait sweep: 'walk' command steers by the top camera toward open-floor waypoints
    Adds gait_sweep.py walk: stands the robot, drives a short forward+turn probe and
    measures what the chassis tag actually did (heading offset and wz sign) so it never
    guesses which way is forward, then steers toward floor-mm waypoints, turning in
    place before advancing and lowering+limping at the end. Refuses up front if the
    chassis tag is not visible (robot tangled / off the open floor) and stops on a
    pinned-leg tilt, a keep-in box exit, or no progress. Pure steering math is tested.
    [gait_sweep.py]
2026-09-19 drive: give the IMU its own freshness cap so a brief stale IMU reading doesn't stop the walk
    The MCU's I2C IMU read intermittently stalls 0.2-0.7 s while the servo bus keeps
    answering (hexapod2 2026-09-10 and 09-18). The drive stream applied the same
    0.15 s freshness bar to imu_age as to pos_age, so a pure IMU blip tripped
    'feedback stale during stream' and held/limped a healthy walker -- cutting walk
    exposures to ~1 s. imu_ok only checks the IMU sample is present, not its age, so
    holding the last attitude for a few hundred ms is harmless; only encoder
    (position) freshness is safety-critical.
    Adds DRIVE_IMU_MAX_AGE_S = 1.0 and applies it to the three age gates
    (snapshot_freshness_error, the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
    [rl_policy.py]
2026-09-19 fleet+gait_sweep: surface dead IMU in status; make sweep resilient to transient IMU/web blips
    fleet.py status now reports IMU liveness per robot: age 65534 ms (I2C-hung
    sentinel) prints 'IMU DEAD -> power-cycle the board', > 1 s prints stale. This
    was the confusion that cost the most time — a dead IMU (positions fine) looks
    like nothing until you read max_imu_source_age_ms.
    gait_sweep.py: _req retries a few times on transient connection errors so a brief
    web restart / mDNS blip doesn't abort a whole run; the walk preflight re-reads
    through a transient implausible/stale IMU sample (up to ~3 s) before aborting.
    [fleet.py, gait_sweep.py]
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2026-09-20 sim: default to validated power-based servo-current model (keep stall trip)
    The sim servo-current estimate was min(|torque|*1.2, 3.0) — a "rail image"
    of actuator torque that overstates holding/stance current ~20x (a real
    STS3215's ~345:1 non-backdrivable gearbox holds a static load at ~0
    current). Replace the DEFAULT with the validated mechanical-power model
    fitted 2026-09-19 (/tmp/gaitval, survey gaits 1-4,7,10 vs the robots'
    walk_summary current_mean_a):
    per-joint current = iq_bus/18 + k * |joint_torque * joint_velocity|
    iq_bus = 0.19 A, k = 0.02282 A/W, then the same 0.1 s low-pass.
    Flag direction per operator: NEW model is the default. bus.current_model:
    power (def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
    [config.yaml]
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2026-09-20 rl_move: complete prev_prev_action plumbing + single attitude-alpha source
    - mjx_host SNAP_ATTRS: snapshot/restore _prev_prev_action on the MJX pool-
    restore path (otherwise Δ²action would cross episodes when the knob is on).
    - SimHexapodJointGoalEnv: initialize _prev_prev_action alongside _prev_action.
    - DeployedTransport.from_cfg: fall back to sensing.attitude_alpha so one knob
    drives training, the inline sim filter, and the hardware-transport filter
    (default 0.98 bit-exact).
    - config.yaml: correct the attitude-alpha doc (no per-episode DR over alpha;
    add drift-offset numbers) and widen the no-op mass_scale in the DR preset.
    - tests: add DR-preset launchability check and a sim bo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
    [config.yaml]
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
